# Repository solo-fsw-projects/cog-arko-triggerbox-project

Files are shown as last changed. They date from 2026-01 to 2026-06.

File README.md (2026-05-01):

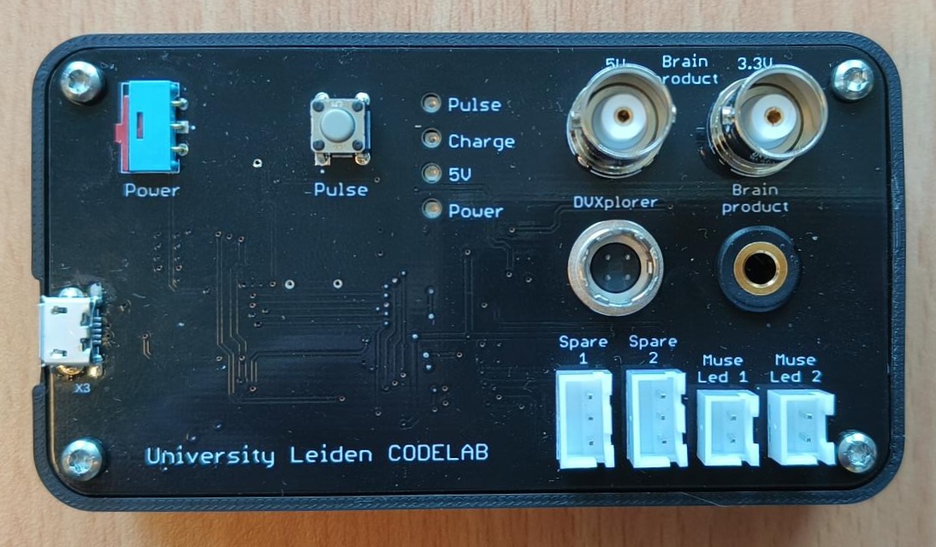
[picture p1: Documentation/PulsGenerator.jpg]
Pulsgenerator


## Description
The pulse generator is designed to synchronize different devices in the Codelab.<br>
Synchronization is based on a simple principle: all devices receive a pulse every 60 seconds.

## Hardware description
The device currently provides ports for Brain Products (3 ports), DVXplorer (1 port), Muse (2 ports), and Spare (2 ports).<br>
Different voltage levels (3.3V or 5V) are supported. For the Spare ports, the voltage can be configured by placing the appropriate resistors on the PCB.<br>
The device is powered by an internal rechargeable Li-ion battery.

## Operation
After powering up, the device sends **three pulses** to indicate startup.<br>
A manual pulse can be triggered by pressing the button; this generates **two pulses**.<br>
Every 60 seconds, a synchronization **one pulse** is sent automatically.<br>
It is also possible to send **5 to 9** pulses via the serial port for special events.<br>

## Serial events
Serial communication requires an Arduino driver. On modern Windows systems, this driver is usually installed automatically.<br>
The serial port must be opened with the following settings: 9600 baud, 8 data bits, no parity, 1 stop bit (9600, 8N1).<br>
Send ASCII characters 5, 6, 7, 8, or 9 to generate the corresponding number of pulses.<br>

## Pulse timing
Each pulse has a width of 100 ms.<br>
If multiple pulses are sent, the interval between pulses is 150 ms.<br>

## Serial Connection
The serial port must be opened with the following settings: 9600 baud, 8 data bits, no parity, 1 stop bit (9600, 8N1)<br>
Send ASCII characters 5, 6, 7, 8, or 9 to generate the corresponding number of pulses.<br>

The UsbParMarker can operate in two modes: **Data Mode** and **Command Mode**. In Command mode, it can execute various functions. Changing between functions is done by (re)opening the serial port using different baud rates:

 - **Data Mode**: 9600 baud.
 - **Command Mode**: 4800 baud.

### Command Mode
In command mode, the UsbParMarker can execute various commands:

| Function | Command | Returns | Type |Note
| --- | --- | --- | --- | --- |
| Version  | V |Json String with device info |string| |
| Ping  | P | Pong,Device | string ||

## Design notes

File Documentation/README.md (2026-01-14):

# Requirements

Trigger box: something that generates intermittent TTL pulses (say every minute) to help synchronize the clocks of our various tools
1.	Box to LED light flash for Muse 
2.	Box to BNC  - for brain products 
3.	Box to Audio - for brain products [3-pin 2.5 mm phone jack; TTL (LVTTL) signals, 0 to +5 V (+ 3.3 V); active low]
4.	Box to DVXplorer  
i.	https://docs.inivation.com/hardware/hardware-advanced-usage/external-camera-sync.html
[The INPUT_SIGNAL port can be configured to detect rising edges, falling edges and pulses originating from another camera or electronic system, and when it detects such an occurence, a special data point is inserted into the data stream coming from the iniVation camera, with a very precise timestamp, allowing data from the camera to be put in relation with events happening externally.]
ii.	The pin lay out is also in the link above - our camera is DVXplorer 

# Hardware description
Hardware is based on the Adafruit Feather 32u4 operating add 3.3V.<br />
Battery power operated with buildin charger.<br />
Step up convertor 3.3V to 5V.<br />
Buffered 3.3V and 5V output's for pulse.

# Arduino ide
Add [board package](https://adafruit.github.io/arduino-board-index/package_adafruit_index.json) to the arduino ide.<br />
Source: [Adafruit](https://learn.adafruit.com/adafruit-feather-32u4-basic-proto/arduino-ide-setup)

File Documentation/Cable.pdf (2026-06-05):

1. Green
2. Yellow
3. White
4. Brown

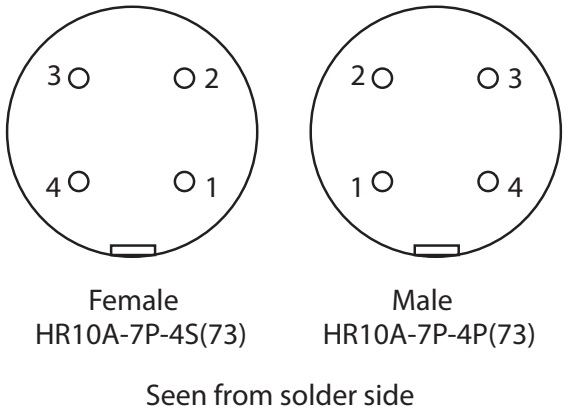
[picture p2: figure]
Female; Male; Seen from solder side

Strip cable 8mm, wires 2mm
Close strain relief with bnc crimptool .213

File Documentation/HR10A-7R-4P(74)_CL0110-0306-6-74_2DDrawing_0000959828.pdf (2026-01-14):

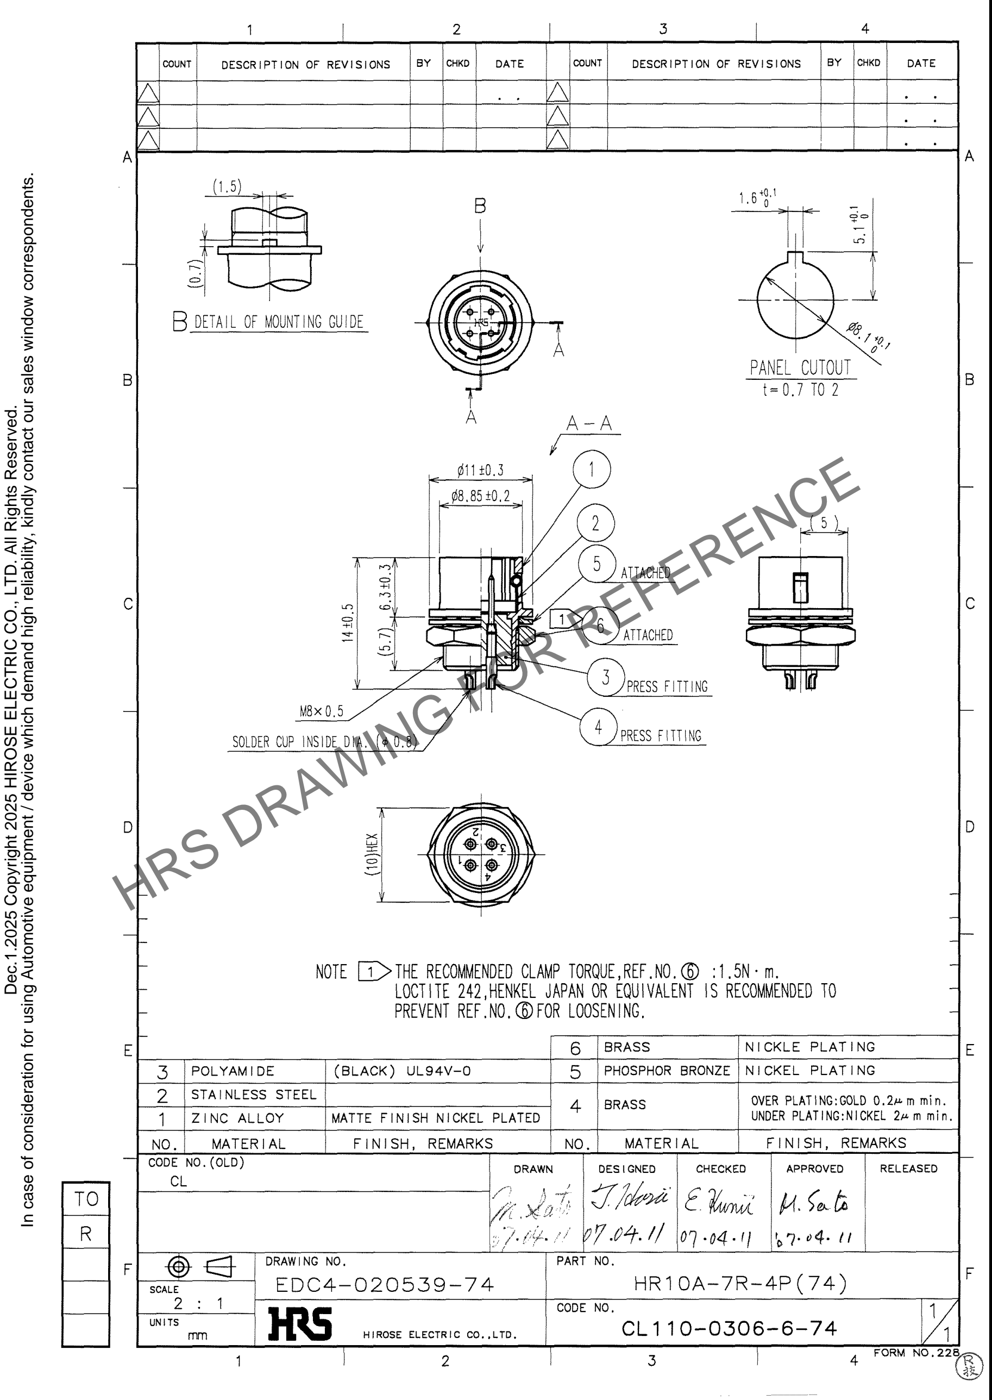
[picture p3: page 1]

HRS DRAWING FOR REFERENCE

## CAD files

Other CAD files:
Hardware/Enclosure/Enclosure.f3d
Hardware/Pcb/PulsGenerator.f3d

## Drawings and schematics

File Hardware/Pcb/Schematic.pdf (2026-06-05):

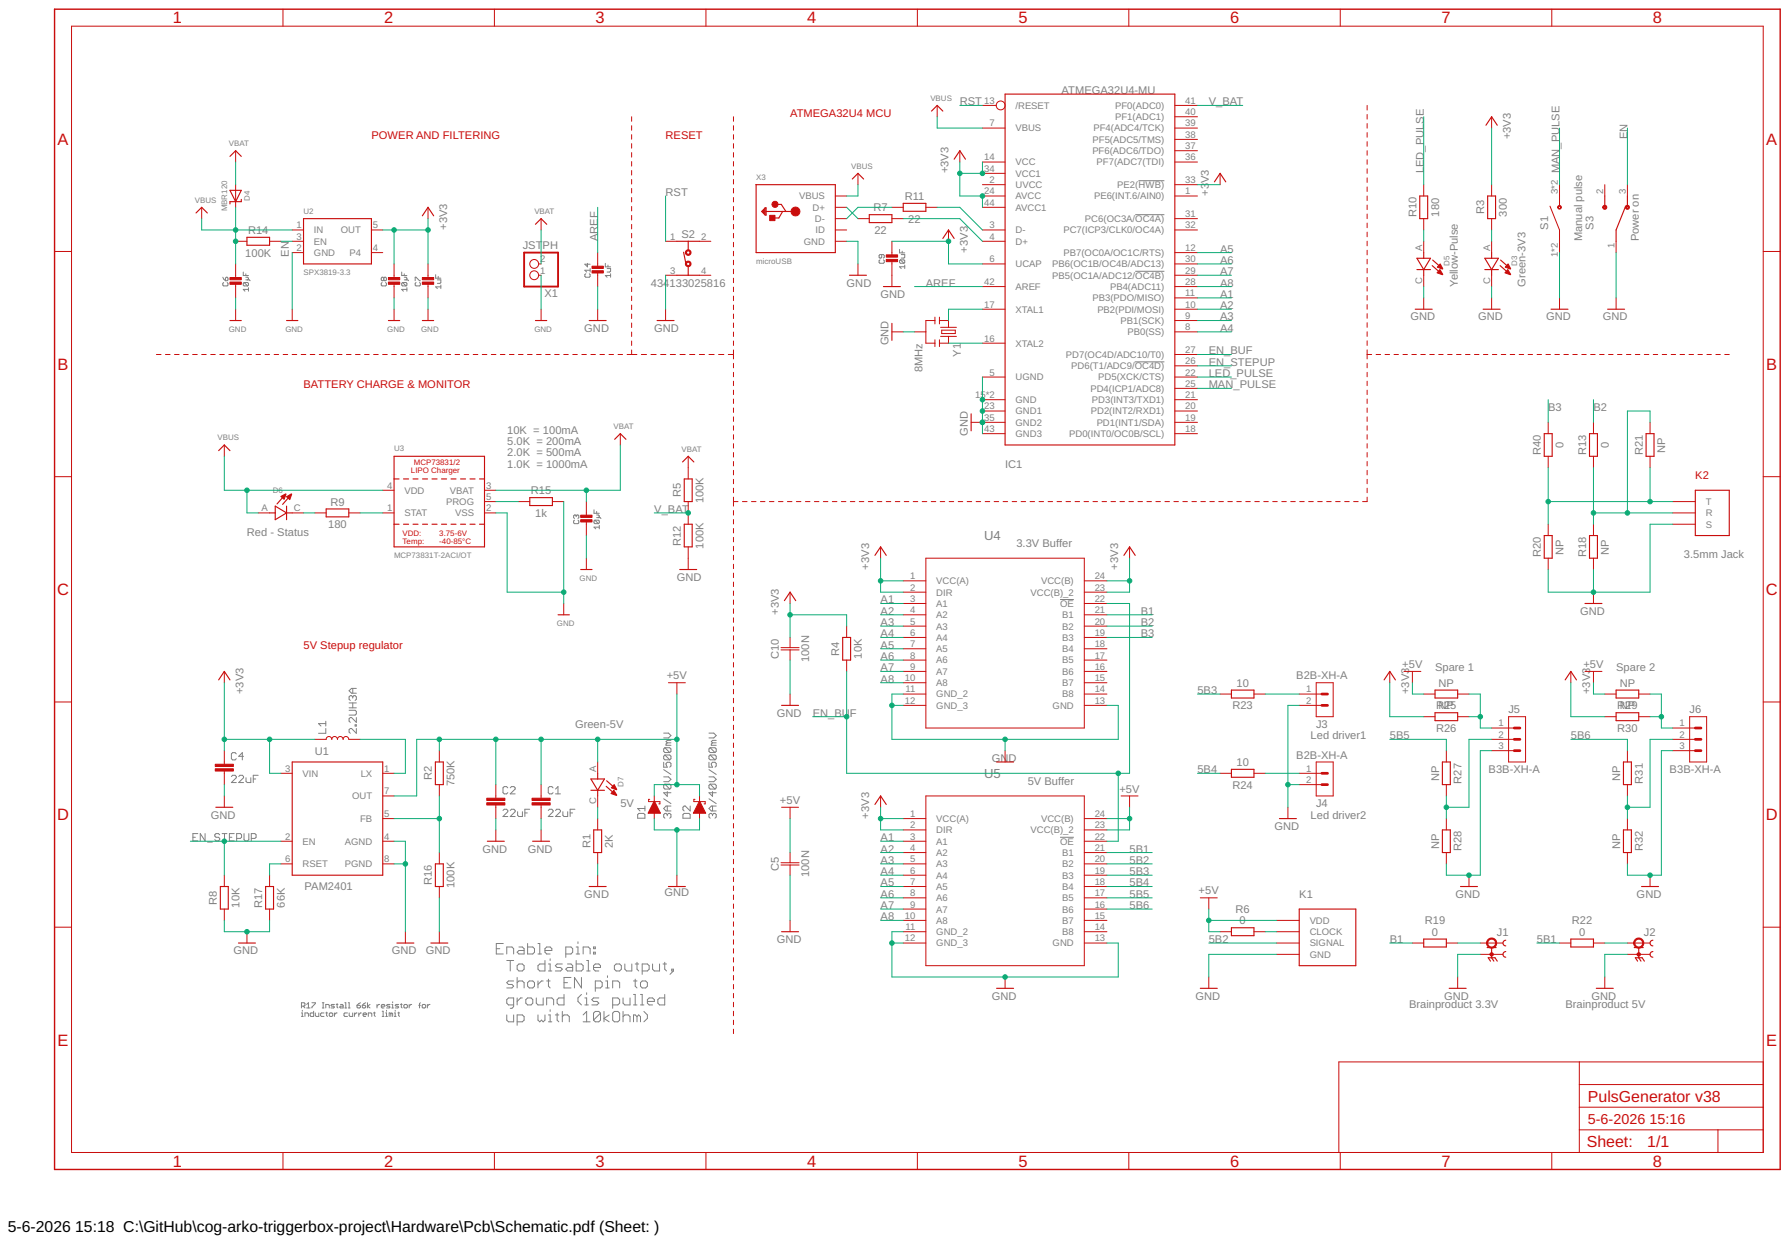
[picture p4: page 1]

Green-3V3Manual pulse Power on

5-6-2026 15:18 C:\GitHub\cog-arko-triggerbox-project\Hardware\Pcb\Schematic.pdf (Sheet: )

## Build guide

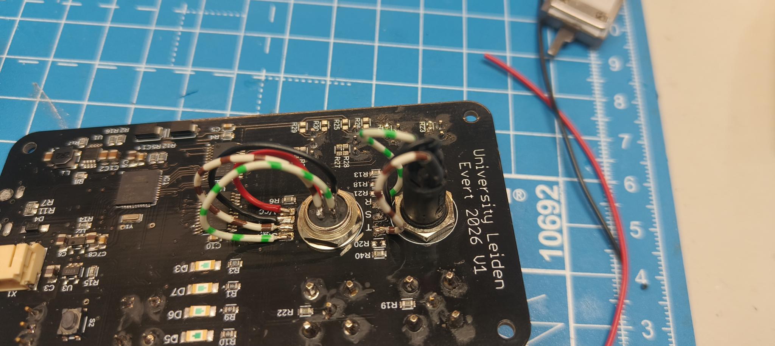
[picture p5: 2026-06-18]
Documentation/Wiring1.jpg

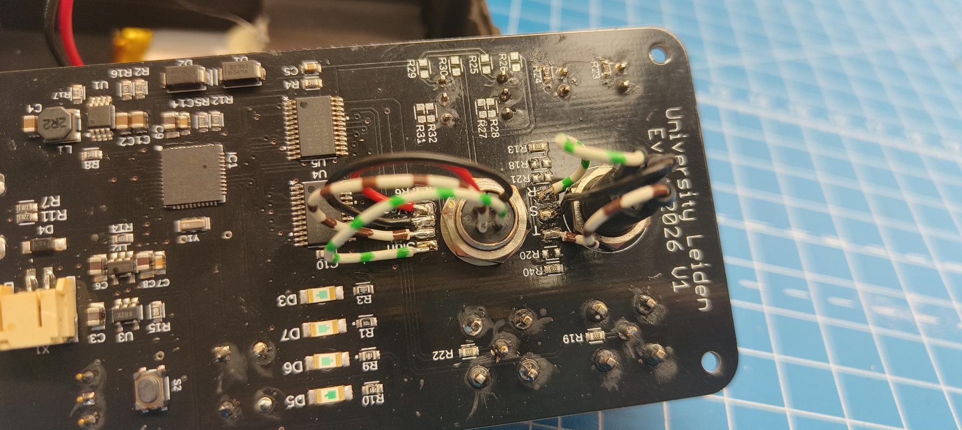
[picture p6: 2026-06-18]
Documentation/Wiring3.jpg

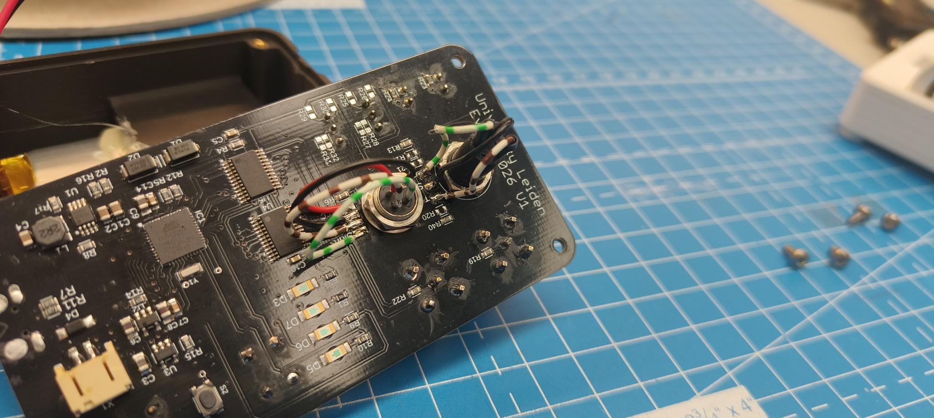
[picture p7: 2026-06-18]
Documentation/Wiring2.jpg

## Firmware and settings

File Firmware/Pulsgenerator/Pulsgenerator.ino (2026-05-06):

/*
Puls Generato Arko Ghosh Codelab for HW version 1
Adafruit Feather 32u4 @ 8Mhz
No need to disable the TXLED in the Feather, already done by Adafruit
Add link https://adafruit.github.io/arduino-board-index/package_adafruit_index.json to boardmanager in preferences to install correct board

20260420  1.0 Initial release

*/

#include <EEPROM.h>
#include <ButtonDebounce.h> //https://github.com/maykon/ButtonDebounce

//define
#define MANUAL_PULSE_BUTTON 4  //PD4
#define LED_PULSE 30           //PD5
#define ENABLE_STEPUP 12       //PD6  3.3V to 5V setup regulator enable
#define ENABLE_BUFFER 6        //PD7  Enable buffers, Note Inverted logic LOW=on, HIGH=off
#define V_BAT A5               //ADC0 It doesn't make much sense to measure battery voltage when connected to pc over usb (it's always charging then and will not give Vbat therefore), but it's implemented


//Globals
const String SwVer = "SW1.0";
const String Version;
const String Serialno;
const String HwVer;
unsigned long time_now = 0;
unsigned int PULSE_INTERVAL = 60*1000;  //ms

//Instance
ButtonDebounce button(MANUAL_PULSE_BUTTON, 10);

void setup() {
  //writeStringToEEPROM(10, "S02037");  //Use ones to program te serial number in the eeprom of the device
  //writeStringToEEPROM(20, "HW1");     //Use ones to program the hardware version in the eeprom of the device
  pinMode(LED_PULSE, OUTPUT);
  pinMode(ENABLE_STEPUP, OUTPUT);
  pinMode(ENABLE_BUFFER, OUTPUT);

  DDRB = 0xFF;  //PortB all pins output
  PORTB = 0x00;
  Serial.begin(9600);  // opens serial port, sets data rate to 9600 bps
  Serialno = readStringFromEEPROM(10);
  HwVer = readStringFromEEPROM(20);
  Version = String(HwVer + ":" + SwVer);  //Set HW version always
  button.setCallback(buttonChanged);      //Callback sub switch for marker sending
  delay(2000);
  digitalWrite(ENABLE_STEPUP, HIGH);      //Enable 5V stepup regulator
  digitalWrite(ENABLE_BUFFER,LOW);        //Inverted LOW=on, HIGH=off
  delay(2000);                            //Wait a moment until 5V stable
  sendPulses(3);                          //3 pulses indicating start up of this device
}



void loop() {
  time_now = millis();

  while (millis() < time_now + PULSE_INTERVAL) {  //Main loop, non blocking
    button.update();                              //scan Trigger button

    if (Serial.baud() == 9600) {  //data mode
      if (Serial.available() > 0) {
        int temp = Serial.read();
        if (temp > 52 && temp < 58) {  //Data betweeen ascii-53 (5) and ascii-57 (9).
          sendPulses(temp - 48);       //Convert ascii to int and send pulses 5~9
        }
      }
    } else if (Serial.baud() == 4800) {  //command mode

      if (Serial.available() > 0) {
        handlecommands();
      }
    }
  }
  sendPulses(1);  // Send every PULSE_INTERVAL 1 puls, 1 puls only
}

void sendPulses(byte Pulses) {
  for (int i = 1; i <= Pulses; i++) {
    digitalWrite(LED_PULSE, HIGH);
    PORTB = 255;
    delay(100);
    digitalWrite(LED_PULSE, LOW);
    PORTB = 0;
    delay(150);
  }
}

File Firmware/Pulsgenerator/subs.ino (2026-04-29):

void writeStringToEEPROM(int addrOffset, const String &strToWrite) {
  byte len = strToWrite.length();
  EEPROM.write(addrOffset, len);
  for (int i = 0; i < len; i++) {
    EEPROM.write(addrOffset + 1 + i, strToWrite[i]);
  }
}

String readStringFromEEPROM(int addrOffset) {
  int newStrLen = EEPROM.read(addrOffset);
  char data[newStrLen + 1];
  for (int i = 0; i < newStrLen; i++) {
    data[i] = EEPROM.read(addrOffset + 1 + i);
  }
  data[newStrLen] = '\0';  // the character may appear in a weird way, you should read: 'only one backslash and 0'
  return String(data);
}

void DumpMyInfo() {
  Serial.print("{\"Version\":\"");
  Serial.print(Version);
  Serial.print("\",");
  Serial.print("\"Serialno\":\"");
  Serial.print(Serialno);
  Serial.print("\",");
  Serial.println("\"Device\":\"Pulsgenerator\"}");
  //Serial.write(ETX);
}

void handlecommands() {
  switch (Serial.read()) {
    case 'V':
      DumpMyInfo();
      break;
    case 'P':
      Serial.println("Pong,Pulsgenerator");
      break;

    default:
      Serial.println("Unknown command");
      break;
  }
}


void buttonChanged(int state) {  //Manual button trigger handeling

  if (state == 0) {  //Button pressed
    sendPulses(2);  //Manual pulse
  }
   else {
  }
}

float batteryvoltage(){         //It doesn't make much sense to measure battery voltage when connected to pc over usb. 
  float measuredvbat = analogRead(V_BAT);
  measuredvbat *= 2;    // Multiply by 2 because of the voltage divider
  measuredvbat *= 3.3;  // Multiply by 3.3V, our reference voltage
  measuredvbat /= 1024; // Convert to voltage
  return measuredvbat;
}
